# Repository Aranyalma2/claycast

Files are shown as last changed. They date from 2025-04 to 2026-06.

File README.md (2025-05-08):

<p align="center">
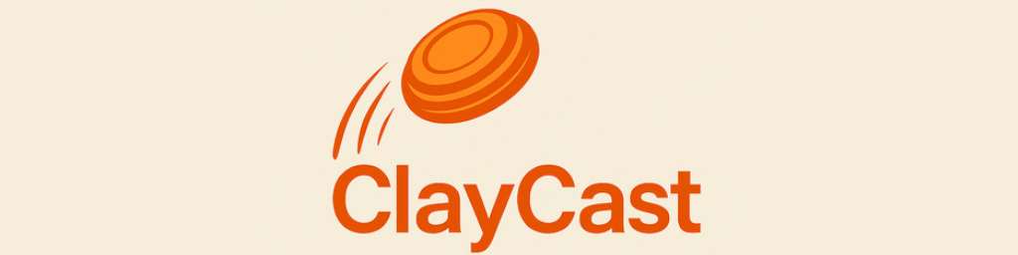
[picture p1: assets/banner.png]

</p>
<p align="center">



</p>

**ClayCast** is a modular wireless control system for clay pigeon shooting ranges.  
It enables field centralized game management via a touchscreen **HMI device**, which controls up to 10 clay thrower machines through a wireless **Modbus RTU** network.  
Communication is handled by **controller node** that act as wireless relays to **client devices** attached to each clay thrower.

## 🎯 Features

- **Modular, multi-device architecture**: HMI (master), Controller (relay), and Client (thrower control)
- **Game management interface** via 7-inch touchscreen HMI
  - Enable/Disable machines (up to 10)
  - Pre-configure next game (max throw, double, triple)
  - Monitor clay disk levels with low-ammo alarms
  - Game screen
  - Summary screen
- **Wireless Modbus RTU bridging** over HC12 (~433MHz)
  - Up to **255 clients** per controller (practically limited to fewer)
  - Reliable full-frame encapsulation (no packet fragmentation)
- **Low-latency protocol** using UART and lightweight firmware
- Built with **Arduino framework**, **Atmega328p**, **ESP32**, and **HC12 modules**
- **Open and customizable** — easy to extend or adapt for other range configurations

## 🧩 Core Components

**ClayCast** consists of three main components:

### 💠 HMI Device
- Acts as the **Modbus RTU Master**
- Human-Machine Interface with touchscreen
- Controls up to **10 clay thrower machines**
- Manages and runs the **preconfigured game**
- Monitors **ammo levels** and triggers alarms if low
- Central command and monitoring unit for the entire system  
[More about here](hmi/README.md)

### 🔸 Controller
- Acts as a wireless Modbus RTU bridge
- Receives Modbus requests from a master device via UART (RS485)
- Encapsulates and broadcasts packets wirelessly to clients
- Receives wireless responses, decapsulates, and forwards them to the master  
[More about here](controller/README.md)

### 🔹 Client
- Identified by a unique Modbus slave address
- Controls an individual clay thrower machine
- Listens for Modbus requests, executes commands (e.g., fire), and returns status
- Response-only device; never initiates communication  
[More about here](client/README.md)

## 📡 Communication Flow

1. HMI sends Modbus RTU request to Controller via UART (RS485).
2. Controller encapsulates and transmits over HC12 radio.
3. Target Client receives, executes, and responds.
4. Controller decapsulates and returns response to HMI.

## 🛠️ Hardware Requirements

- **HMI Device**:
  - Kinco HMI [GL070E](https://en.kinco.cn/productdetail/gl070e90.html)

- **Controller**:
  - Arduino (Atmega328p)
  - HC12 radio module
  - RS485 interface to HMI (Modbus master)

- **Client**:
  - Arduino (Atmega328p)
  - HC12 radio module
  - Clay thrower trigger mechanism (relay, microswitch, etc.)

## 📦 Modbus Support

Clients implement:
- **Trigger register** – Fire the clay thrower
- **Status registers** – Report state, diagnostics, or ammo level

## 🚧 Status & Development Milestones

🛠️ Currently Under Development — Working Prototype Deployed in Test Field

- ✅ **Prototype Hardware Evaluation**  
  Initial testing and validation of temporary hardware components.

- ✅ **Firmware Architecture Design**  
  Core structure and logic for both controller and client firmware defined and implemented.

- ✅ **Interim Hardware Integration**  
  Temporary hardware assembled and tested for early firmware and communication debugging.

- ✅ **Wireless Communication Tester**  
  Radio signal testing module completed to assess transmission range and reliability.

- 🔧 **Final Hardware Assembly** *(In Progress)*  
  Development and deployment of production-ready, dedicated hardware.
  
- 🚀 **Human-Machine Interface (HMI)** *(In Testing)*  
  - Game customizability, fire control, data logging  
  - Ammo monitoring with alarms  
  - Controls up to 10 clay throwers

## 🔀 Alternative use

Create a Modbus RTU bridge over the air with 2 or more **Controllers**. However, radio medium usage is not controlled, so it is easy to cause interference. Incidentally it does not include any error detection and/or correction, leaving everything to the application layer protocol.
Not ready for any production usage.

---

## 📜 License

This project is licensed under the MIT License. See the [LICENSE](LICENSE.md) file for details.

---

## 🤝 Contributions

Made with ❤️ by <a href="https://github.com/Aranyalma2" target="_blank">Aranyalma2</a>

This is a self-maintained project. Feel free to use, fork, or modify it. Feedback and suggestions are always welcome!

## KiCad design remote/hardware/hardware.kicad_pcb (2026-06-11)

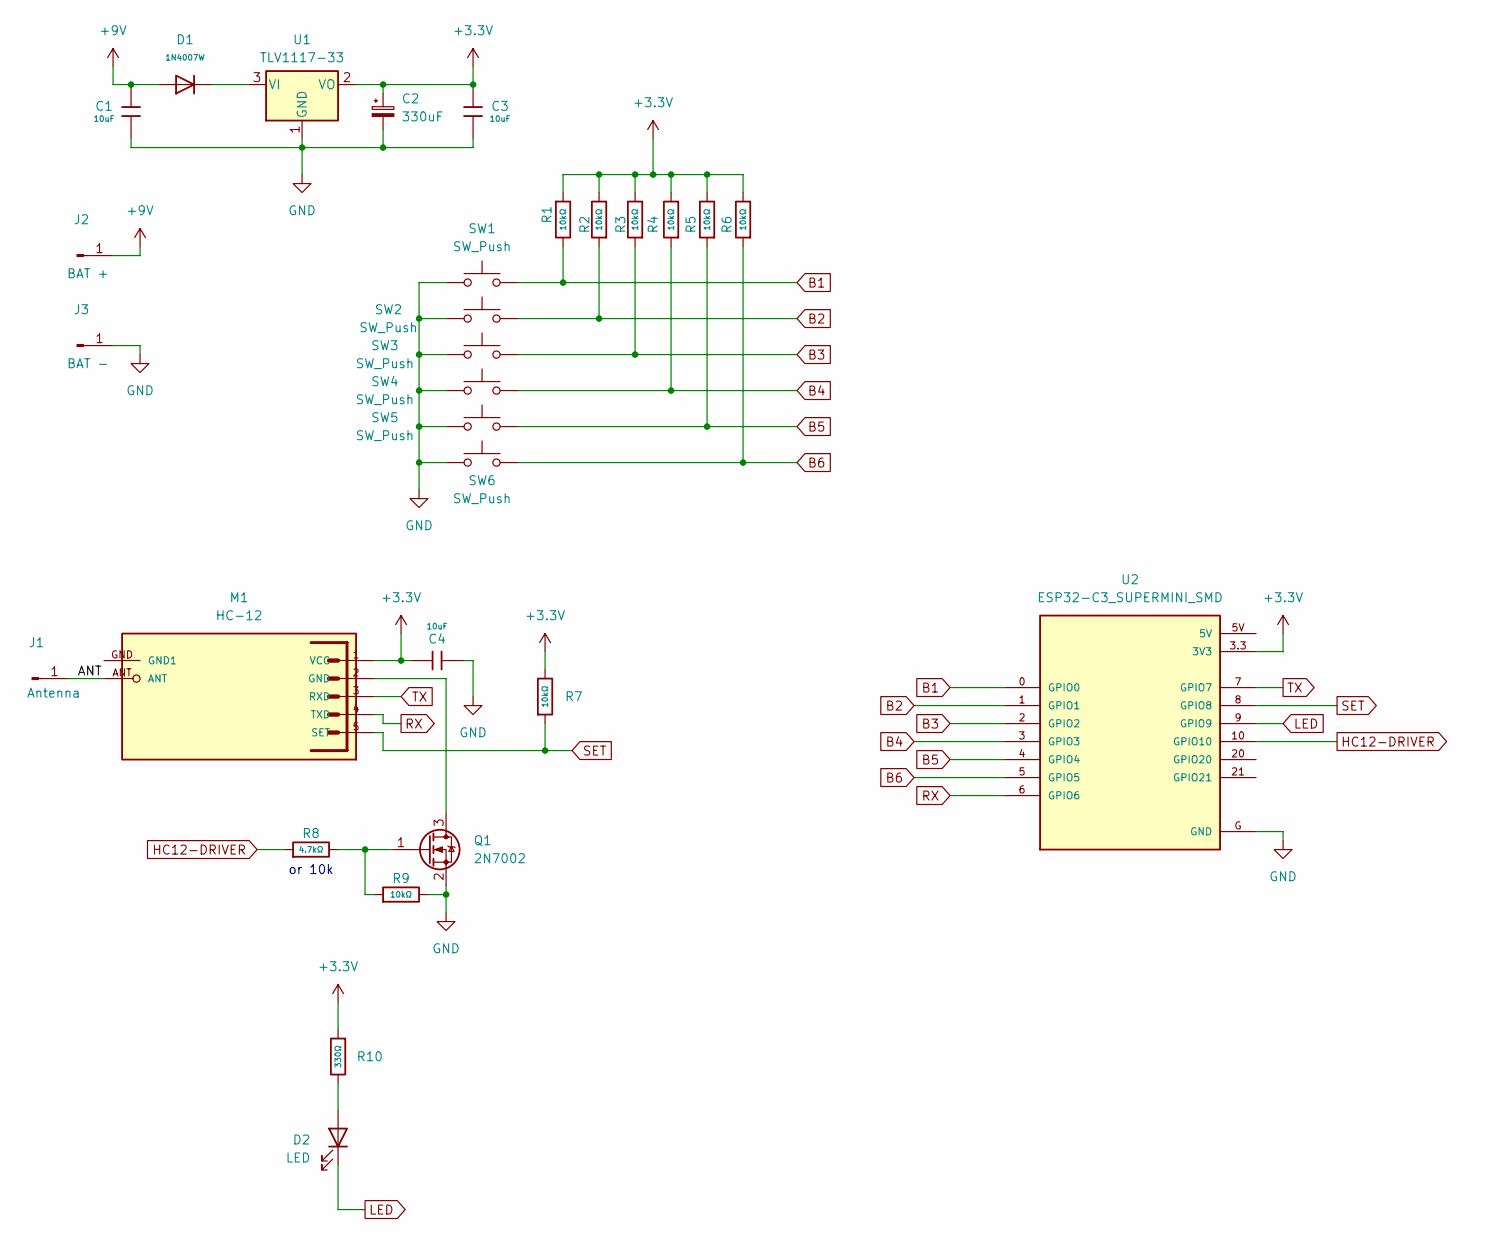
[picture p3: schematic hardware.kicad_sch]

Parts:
C1, C3, C4: 10uF; C_1206; Voltage Rated 6V; Tolerance ±10%; Part CL31A106KBHNNNE; LCSC C13585
C2: 330uF; CP_Radial_D6.3mm_P2.50mm
D1: 1N4007W; D_SMB; Part 1N4007W; LCSC C18199088
D2: LED; LED_1206_3216Metric_Pad1.42x1.75mm_HandSolder
J1: Antenna; PinHeader_1x01_P1.00mm_Vertical
J2: BAT +; PinHeader_1x01_P1.00mm_Vertical
J3: BAT -; PinHeader_1x01_P1.00mm_Vertical
M1: HC-12; MA05-1
Q1: 2N7002; SOT-23
R1, R2, R3, R4, R5, R6, R7, R9: 10kΩ; R_0805; Overload Voltage (Max) 200V; Tolerance ±1%; Part 1206W4F1002T5E; LCSC C17902
R8: 4.7kΩ; R_0805; Overload Voltage (Max) 200V; Tolerance ±1%; Part 1206W4F1002T5E; LCSC C17902
R10: 330Ω; R_1206
SW1, SW2, SW3, SW4, SW5, SW6: SW_Push; SW_Push_1P1T_NO_E-Switch_TL3301NxxxxxG
U1: TLV1117-33; TO-252-2
U2: ESP32-C3_SUPERMINI_SMD; MODULE_ESP32-C3_SUPERMINI

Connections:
+3.3V: C2.1, C3.1, C4.1, M1.1 (VCC), R1.1, R2.2, R3.2, R4.2, R5.2, R6.2, R7.2, R10.1, U1.2 (VO), U2.3.3 (3V3)
+9V: C1.1, D1.2, J2.1
/ANT: J1.1, M1.ANT
B1: R1.2, SW1.1, U2.0 (GPIO0)
B2: R2.1, SW2.1, U2.1 (GPIO1)
B3: R3.1, SW3.1, U2.2 (GPIO2)
B4: R4.1, SW4.1, U2.3 (GPIO3)
B5: R5.1, SW5.1, U2.4 (GPIO4)
B6: R6.1, SW6.1, U2.5 (GPIO5)
GND: C1.2, C2.2, C3.2, C4.2, J3.1, Q1.2 (S), R9.2, SW1.2, SW2.2, SW3.2, SW4.2, SW5.2, SW6.2, U1.1 (GND), U2.G (GND)
HC12-DRIVER: R8.1, U2.10 (GPIO10)
LED: D2.1 (K), U2.9 (GPIO9)
unnamed: D2.2 (A), R10.2
unnamed: M1.2 (GND), Q1.3 (D)
unnamed: Q1.1 (G), R8.2, R9.1
unnamed: D1.1, U1.3 (VI)
RX: M1.4 (TXD), U2.6 (GPIO6)
SET: M1.5 (SET), R7.1, U2.8 (GPIO8)
TX: M1.3 (RXD), U2.7 (GPIO7)

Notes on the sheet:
or 10k

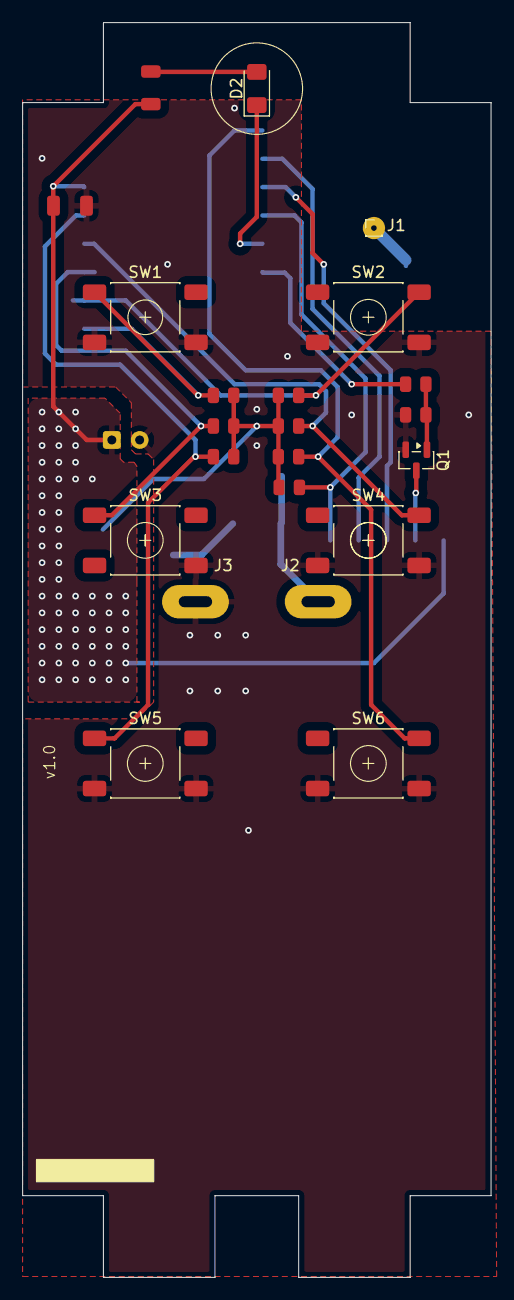
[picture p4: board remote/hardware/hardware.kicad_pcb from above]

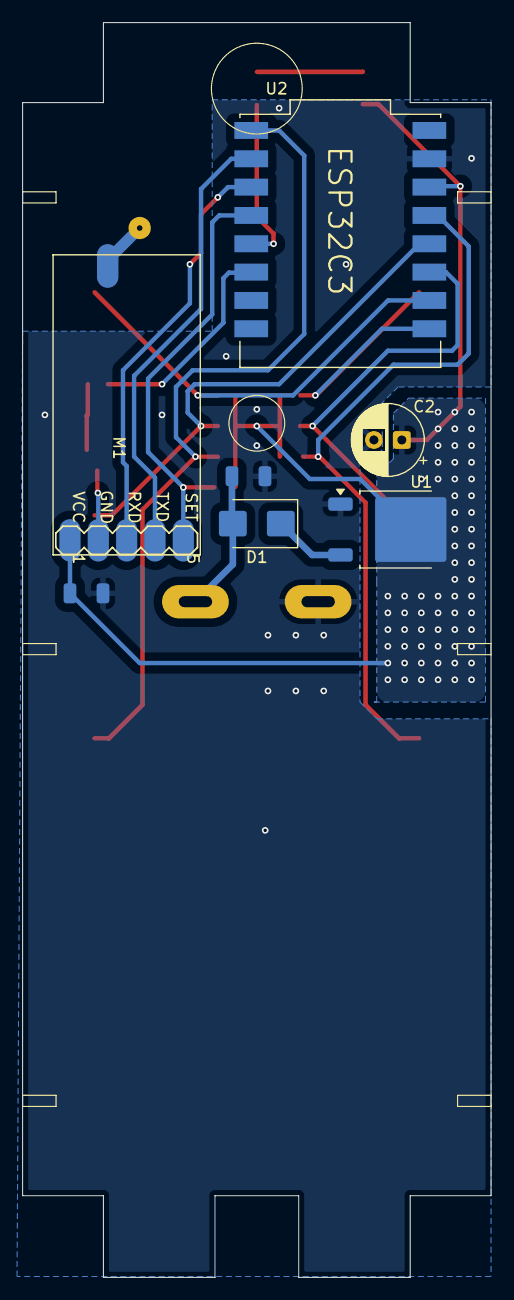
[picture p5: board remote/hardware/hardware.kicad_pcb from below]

Board: 2 copper layers, 42.0 x 112.5 mm, 29 parts (7 on the bottom side), 19 nets.

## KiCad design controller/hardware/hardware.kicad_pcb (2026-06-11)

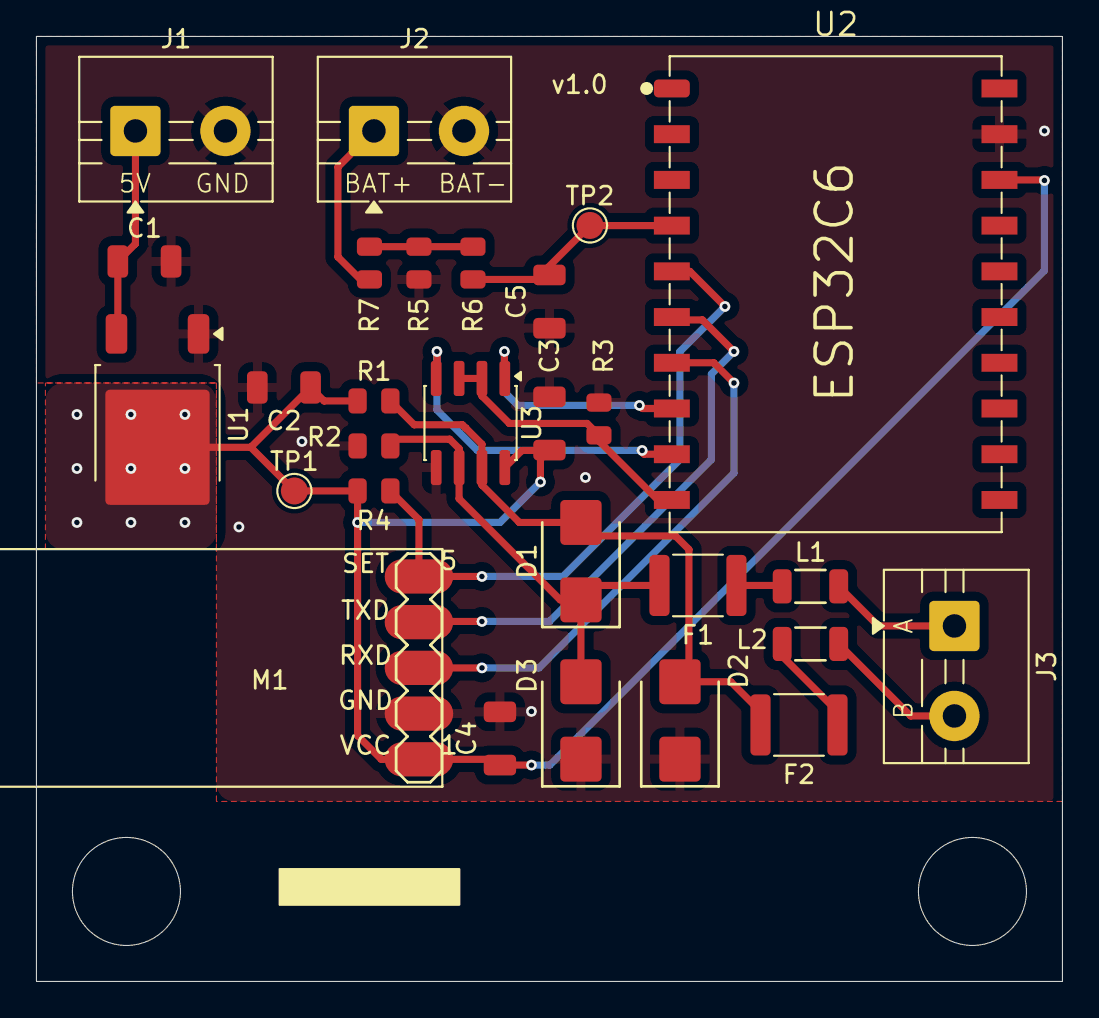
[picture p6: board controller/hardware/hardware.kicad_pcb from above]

Board: 2 copper layers, 57.0 x 52.5 mm, 28 parts (0 on the bottom side), 18 nets.

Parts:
C1, C2, C4: 10uF; C_1206
C3, C5: 100nF; C_1206
D1, D2, D3: SMBJ12CA; D_SMB
F1, F2: BSMD1812-100-30V
J1, J2, J3: Screw_Terminal_01x02; TerminalBlock_MaiXu_MX126-5.0-02P_1x02_P5.00mm
L1, L2: 10uH; L_1206
M1: HC-12; MA05-1
R1, R2, R3, R4: 10kΩ; R_0805
R5: 1MΩ; R_0805
R6: 1kΩ; R_0805
R7: 100kΩ; R_0805
TP1: 3V3; TestPoint_Pad_D1.5mm
TP2: BAT_V; TestPoint_Pad_D1.5mm
U1: TLV1117-33; TO-252-2
U2: ESP32-C6-SuperMini; ESP32-C6-SuperMini_SMD
U3: MAX3485; SOIC-8_3.9x4.9mm_P1.27mm

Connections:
+3.3V: C2.1, C3.1, C4.1, M1.1 (VCC), R1.1, R4.2, TP1.1, U1.2 (VO), U2.13 (3V3), U3.8 (VCC)
+5V: C1.1, J1.1, U1.3 (VI)
+BATT: J2.1, R5.2
BAT_MEASURE: C5.2, R6.1, TP2.1, U2.4 (GPIO1)
GND: C1.2, C2.2, C3.2, C4.2, C5.1, D2.1, D3.1, J1.2, J2.2, M1.2 (GND), R2.2, R3.2, R7.1, U1.1 (GND), U2.12 (GND), U3.5 (GND)
unnamed: F1.2, L1.1
unnamed: F2.2, L2.1
unnamed: R5.1, R6.2, R7.2
unnamed: D1.1, D3.2, F1.1, R2.1, U3.6 (A)
unnamed: D1.2, D2.2, F2.1, R1.2, U3.7 (B)
RS485-1_A: J3.1, L1.2
RS485-1_B: J3.2, L2.2
RX: M1.4 (TXD), U2.6 (GPIO3)
RX1: U2.8 (GPIO5), U3.1 (RO)
SET: M1.5 (SET), R4.1, U2.5 (GPIO2)
TX: M1.3 (RXD), U2.7 (GPIO4)
TX1: U2.9 (GPIO6), U3.4 (DI)
TX1_EN: R3.1, U2.10 (GPIO7), U3.2 (~RE), U3.3 (DE)

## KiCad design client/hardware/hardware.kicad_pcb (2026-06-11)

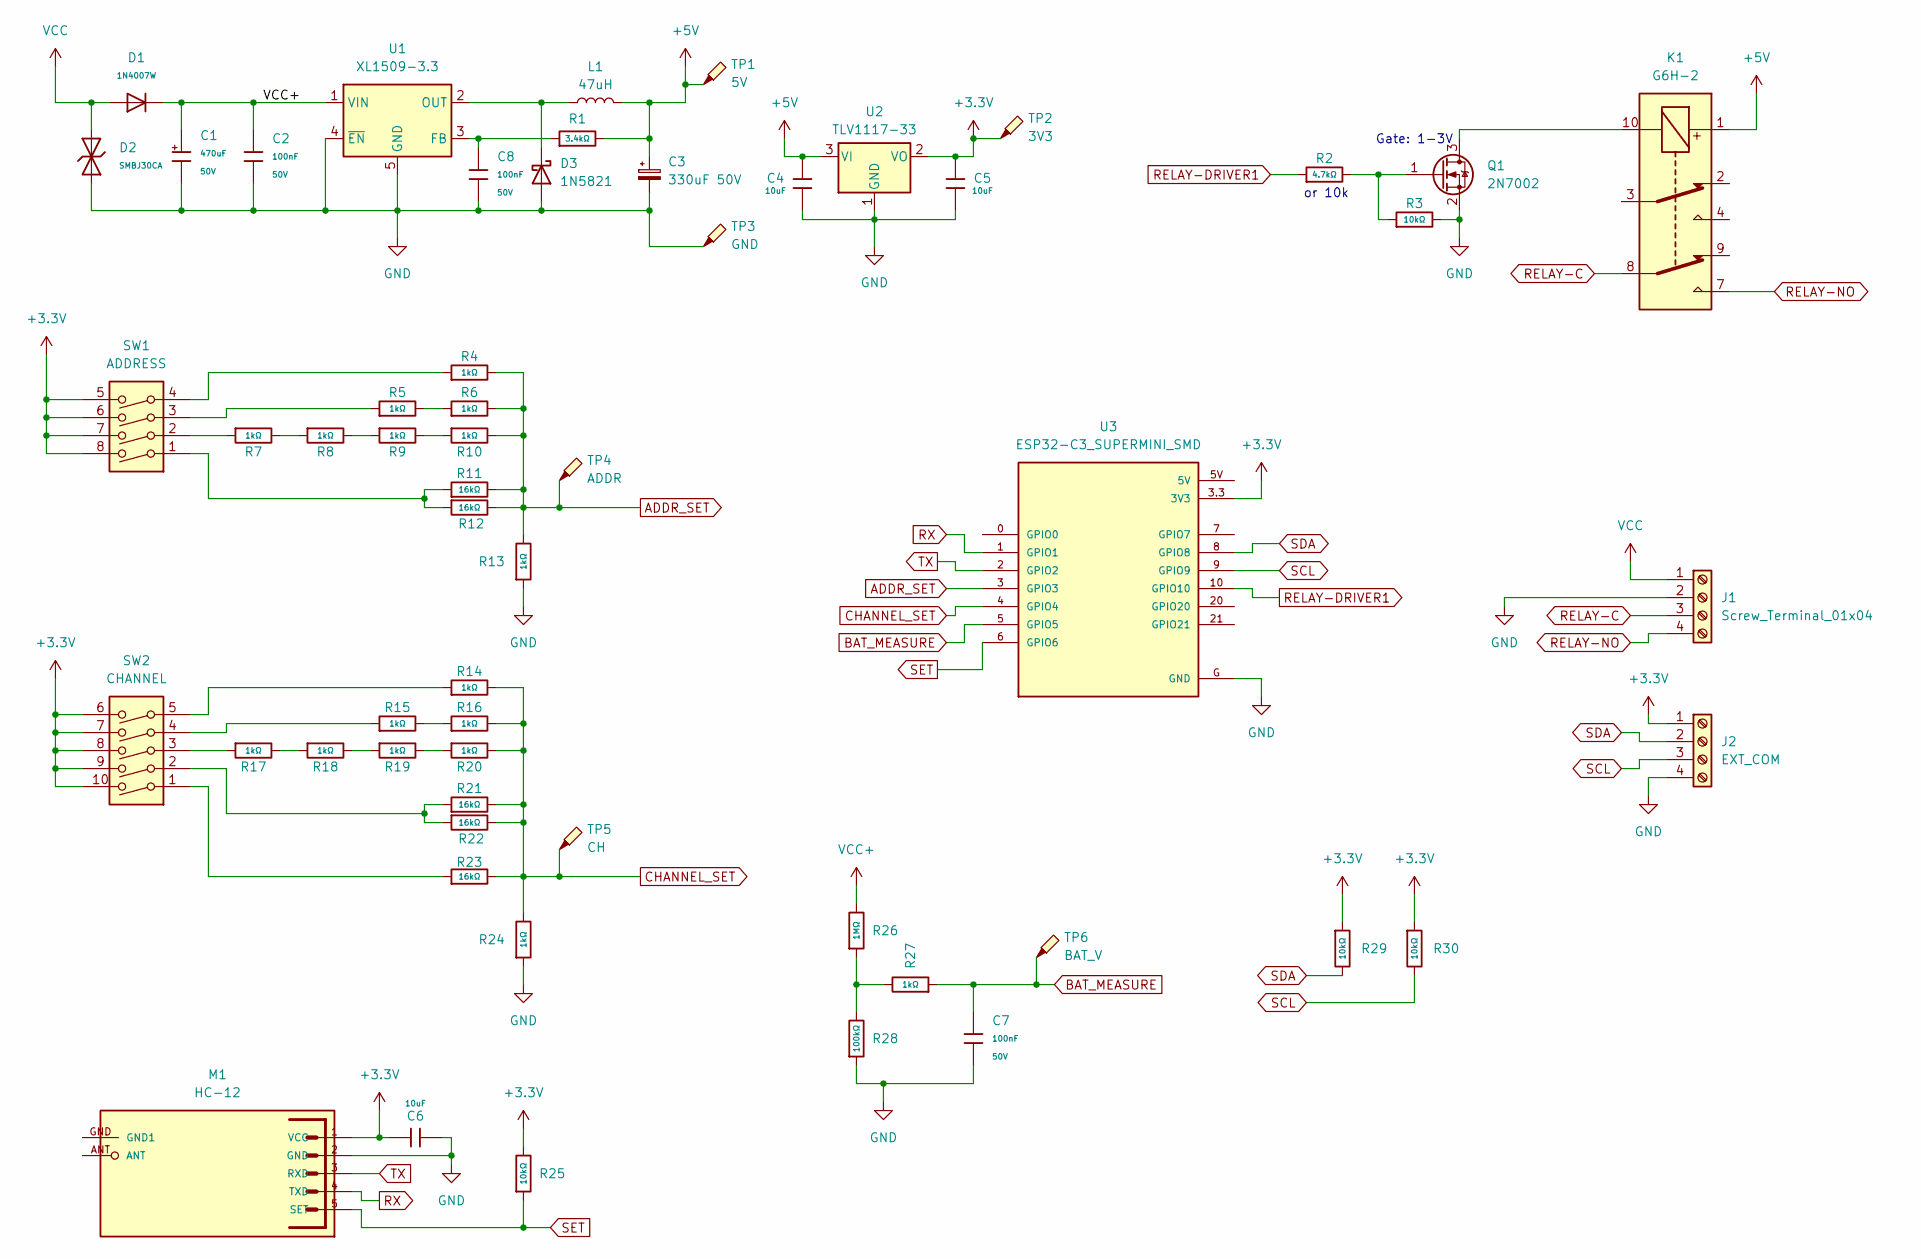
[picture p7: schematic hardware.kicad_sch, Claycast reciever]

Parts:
C1: 470uF; C_Plugin,D10xL16mm; Voltage Rated 50V; Part EGT477M1HG16RRS0P; LCSC C3015599
C2, C7, C8: 100nF; C_1206; Voltage Rated 50V; Tolerance ±10%; Part CL31B104KBCNNNC; LCSC C24497
C3: 330uF 50V; CP_Radial_D6.3mm_P2.50mm
C4, C5, C6: 10uF; C_1206; Voltage Rated 6V; Tolerance ±10%; Part CL31A106KBHNNNE; LCSC C13585
D1: 1N4007W; D_SMB; Part 1N4007W; LCSC C18199088
D2: SMBJ30CA; D_SMB; Breakdown Voltage 33.3V; Part SMBJ30CA; LCSC C2925441
D3: 1N5821; D_SMB
J1: Screw_Terminal_01x04; General Connector 4P 3.5mm - Socket
J2: EXT_COM; JST_PH_B4B-PH-K_1x04_P2.00mm_Vertical
K1: G6H-2; Relay_DPDT_Omron_G6H-2
L1: 47uH; L_Radial_D7.0mm_P3.00mm
M1: HC-12; MA05-1
Q1: 2N7002; SOT-23
R1: 3.4kΩ; R_0805; Overload Voltage (Max) 150V; Tolerance ±1%; Part 0805W8F3303T5E; LCSC C17629
R2: 4.7kΩ; R_0805; Overload Voltage (Max) 200V; Tolerance ±1%; Part 1206W4F1002T5E; LCSC C17902
R3, R25, R29, R30: 10kΩ; R_0805; Overload Voltage (Max) 200V; Tolerance ±1%; Part 1206W4F1002T5E; LCSC C17902
R4, R5, R6, R7, R8, R9, R10, R13, R14, R15, R16, R17, R18, R19, R20, R24, R27: 1kΩ; R_0805; Overload Voltage (Max) 200V; Tolerance ±1%; Part 1206W4F1002T5E; LCSC C17902
R11, R12, R21, R22, R23: 16kΩ; R_0805; Overload Voltage (Max) 200V; Tolerance ±1%; Part 1206W4F1002T5E; LCSC C17902
R26: 1MΩ; R_0805; Overload Voltage (Max) 200V; Tolerance ±1%; Part 1206W4F1002T5E; LCSC C17902
R28: 100kΩ; R_0805; Overload Voltage (Max) 200V; Tolerance ±1%; Part 1206W4F1002T5E; LCSC C17902
SW1: ADDRESS; SW_DIP_SPSTx04_Slide_9.78x12.34mm_W7.62mm_P2.54mm
SW2: CHANNEL; SW_DIP_SPSTx05_Slide_9.78x14.88mm_W7.62mm_P2.54mm
TP1: 5V; TestPoint_Pad_D1.5mm
TP2: 3V3; TestPoint_Pad_D1.5mm
TP3: GND; TestPoint_Pad_D1.5mm
TP4: ADDR; TestPoint_Pad_D1.5mm
TP5: CH; TestPoint_Pad_D1.5mm
TP6: BAT_V; TestPoint_Pad_D1.5mm
U1: XL1509-3.3; SOIC-8_3.9x4.9mm_P1.27mm
U2: TLV1117-33; TO-252-2
U3: ESP32-C3_SUPERMINI_SMD; MODULE_ESP32-C3_SUPERMINI

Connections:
+3.3V: C5.1, C6.1, J2.1, M1.1 (VCC), R25.2, R29.1, R30.1, SW1.5, SW1.6, SW1.7, SW1.8, SW2.6, SW2.7, SW2.8, SW2.9, SW2.10, TP2.1, U2.2 (VO), U3.3.3 (3V3)
+5V: C3.1, C4.1, K1.1, L1.2, R1.2, TP1.1, U2.3 (VI)
ADDR_SET: R4.2, R6.2, R10.2, R11.2, R12.2, R13.2, TP4.1, U3.3 (GPIO3)
BAT_MEASURE: C7.2, R27.1, TP6.1, U3.5 (GPIO5)
CHANNEL_SET: R14.2, R16.2, R20.2, R21.2, R22.2, R23.2, R24.2, TP5.1, U3.4 (GPIO4)
GND: C1.2, C2.2, C3.2, C4.2, C5.2, C6.2, C7.1, C8.2, D2.1, D3.2 (A), J1.2, J2.4, M1.2 (GND), Q1.2 (S), R3.2, R13.1, R24.1, R28.1, TP3.1, U1.4 (~EN), U1.5 (GND), U1.6 (GND), U1.7 (GND), U1.8 (GND), U2.1 (GND), U3.G (GND)
unnamed: D3.1 (K), L1.1, U1.2 (OUT)
unnamed: K1.10, Q1.3 (D)
unnamed: Q1.1 (G), R2.2, R3.1
unnamed: R4.1, SW1.4
unnamed: R5.1, SW1.3
unnamed: R5.2, R6.1
unnamed: R7.1, SW1.2
unnamed: R7.2, R8.1
unnamed: R8.2, R9.1
unnamed: R9.2, R10.1
unnamed: R11.1, R12.1, SW1.1
unnamed: R14.1, SW2.5
unnamed: R15.1, SW2.4
unnamed: R15.2, R16.1
unnamed: R17.1, SW2.3
unnamed: R17.2, R18.1
unnamed: R18.2, R19.1
unnamed: R19.2, R20.1
unnamed: R21.1, R22.1, SW2.2
unnamed: R23.1, SW2.1
unnamed: R26.1, R27.2, R28.2
unnamed: C8.1, R1.1, U1.3 (FB)
RELAY-C: J1.3, K1.8
RELAY-DRIVER1: R2.1, U3.10 (GPIO10)
RELAY-NO: J1.4, K1.7
RX: M1.4 (TXD), U3.1 (GPIO1)
SCL: J2.3, R30.2, U3.9 (GPIO9)
SDA: J2.2, R29.2, U3.8 (GPIO8)
SET: M1.5 (SET), R25.1, U3.6 (GPIO6)
TX: M1.3 (RXD), U3.2 (GPIO2)
VCC: D1.2, D2.2, J1.1
VCC+: C1.1, C2.1, D1.1, R26.2, U1.1 (VIN)

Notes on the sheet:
or 10k
Gate: 1-3V

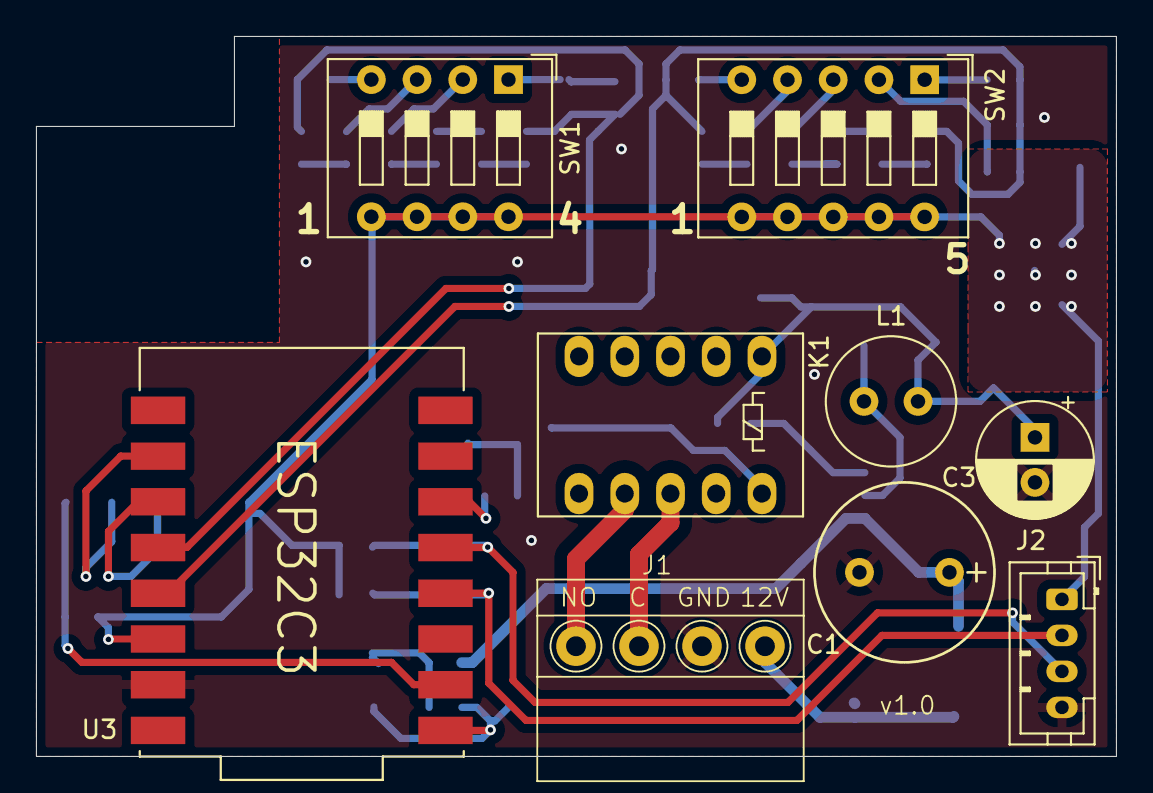
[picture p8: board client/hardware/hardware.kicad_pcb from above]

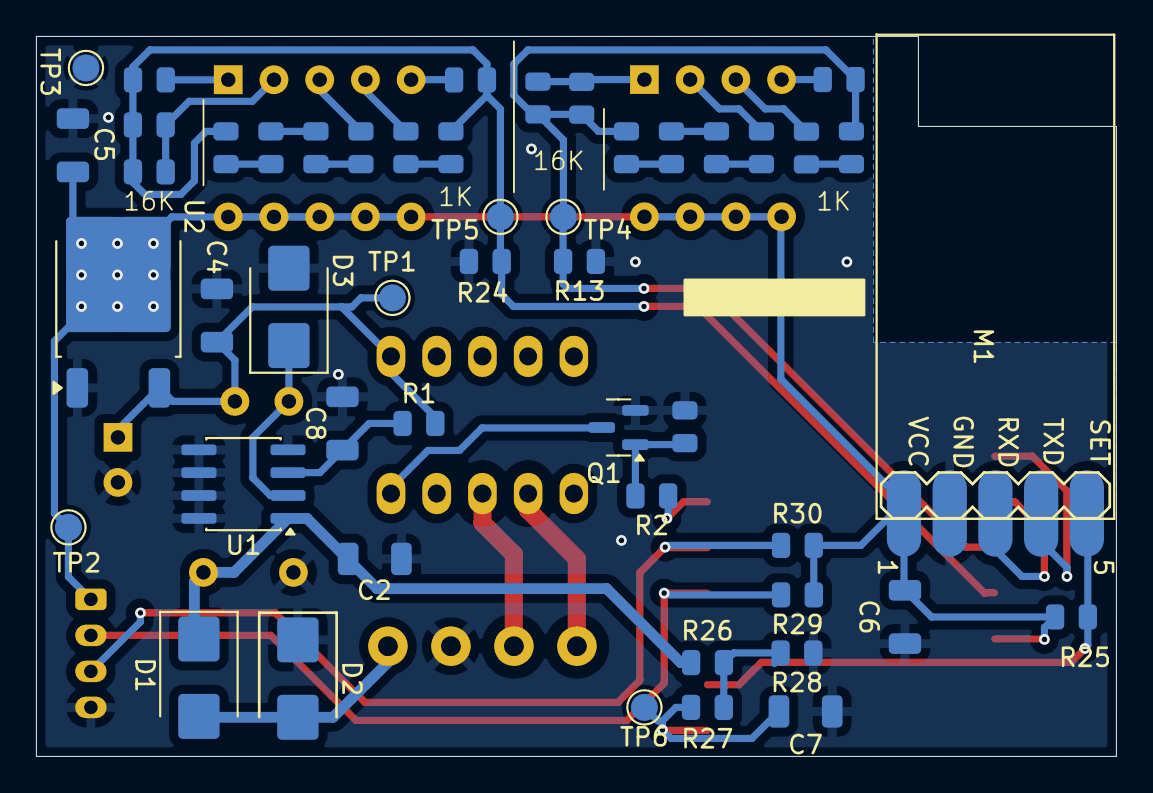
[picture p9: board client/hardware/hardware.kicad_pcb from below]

Board: 2 copper layers, 60.0 x 40.0 mm, 58 parts (49 on the bottom side), 38 nets.

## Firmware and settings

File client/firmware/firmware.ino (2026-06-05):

#include "src/config.h"
#include "src/SetupLoader.h"
#include <Arduino.h>
#include <HC12Transporter.h>

// Encryption key (just for set, but no practical use)
static const uint8_t SHARED_KEY[16] = {
    0xDE, 0xAD, 0xBE, 0xEF, 0xCA, 0xFE, 0xBA, 0xBE,
    0x01, 0x23, 0x45, 0x67, 0x89, 0xAB, 0xCD, 0xEF};

HC12Driver radio;
RadioTransport transport;

uint32_t triggerTime = 0;

// --- onReceive callback (fires from background task) ---
// sendAsync() is safe here. send() is NOT safe here -- it will deadlock.
static void onPacket(uint8_t src, PacketType type,
                     const uint8_t* data, uint8_t len) {
    switch (type) {
        case PacketType::DATA:
        Serial.printf("DATA from 0x%02X (%d bytes)\n", src, len);
        if(len > 1) { return; }
            switch (data[0]) {
                case 0x01:
                    Serial.println(F("Trigger received"));
                    triggerTime = millis();
                    digitalWrite(RELAY_PIN, HIGH);
                    break;
                case 0x02:
                    Serial.println(F("Get Battery"));
                    uint16_t batteryVoltage = SetupLoader::getBatteryVoltage();
                    transport.sendAsync(src, PacketType::DATA, &batteryVoltage, 2);
                    break;
                default:
                    break;
            }
            break;

        case PacketType::PING:
            // Reply with a PONG carrying this node's radio address.
            Serial.printf("PING from 0x%02X -> PONG\n", src);
            {
                // Payload: [mylocal channel and address]
                uint8_t pong[2] = {SetupLoader::getChannel(), SetupLoader::getAddress()};
                transport.sendAsync(src, PacketType::PONG, pong, 2);
            }
            break;

        default:
            break;
    }
}

void setup() {
    Serial.begin(115200);
    SetupLoader::init();

    // --- HC-12 configuration ---

    HC12Config hcCfg = HC12_DEFAULT_CONFIG;
    hcCfg.channel = SetupLoader::getChannel();
    hcCfg.baud = 9600;

    if (!radio.begin(&Serial1, HC12_SET_PIN, HC12_RX_PIN, HC12_TX_PIN, hcCfg)) {
        Serial.println(F("HC-12 init FAILED"));
        delay(2000);
        ESP.restart();
    }
    Serial.println(F("HC-12 OK"));

    // --- Transport configuration ---
    TransportConfig tCfg = TRANSPORT_DEFAULT_CONFIG;
    tCfg.localAddr = SetupLoader::getAddress() + 0x10;
    tCfg.autoPowerEnabled = false;
    memcpy(tCfg.encryptionKey, SHARED_KEY, 16);

    if (!transport.begin(&radio, tCfg)) {
        Serial.println(F("Transport init FAILED"));
        delay(2000);
        ESP.restart();
    }

    transport.onReceive(onPacket);

    if (!transport.startTask()) {
        Serial.println(F("Transport task START FAILED"));
        delay(2000);
        ESP.restart();
    }

    Serial.printf("[SLAVE 0x%02X] Transport ready\n", SetupLoader::getAddress() + 0x10);
}

void loop() {
    if (triggerTime + TRIGGER_TIME < millis()) {
        digitalWrite(RELAY_PIN, LOW);
    }
}

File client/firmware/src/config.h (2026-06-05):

#ifndef __CONFIG_H__
#define __CONFIG_H__

// RADIO PINS
#define HC12_RX 1
#define HC12_TX 2
#define HC12_SET 6

// ANALOG PINS
#define CHANNEL_SET 4
#define NODE_ADDRESS 3
#define BATTERY_MEASUREMENT_PIN 5

// I2C PINS
#define I2C_SDA 8
#define I2C_SCL 9

// RELAY PINS
#define RELAY_PIN 10

// TRIGGER TIME
#define TRIGGER_TIME 1000

#endif  // __CONFIG_H__

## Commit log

2025-04-30 Kinco HMI
    Human machine interface and game controller
    Up to 10 machine
    Support Hungarian language only
    *Use [Kinco DTools V4.5.0.1](https://en.kinco.cn/download/hmisoftware.html)*
    [current_project_name_file.csv]
2026-05-27 remove the v1 files
    [current_project_name_file.csv]
2026-06-05 receiver pcb v1
    [hardware.kicad_pcb, hardware.kicad_sch]
2026-06-05 controller init
    [hardware.kicad_pcb, hardware.kicad_sch]
2026-06-05 update to kicad v9
    [hardware.kicad_pcb, hardware.kicad_sch]
2026-06-05 hw updates
    [hardware.kicad_pcb, hardware.kicad_sch]
2026-06-06 remote init
    [hardware.kicad_pcb, hardware.kicad_sch]
2026-06-11 final v1.0 hardware
    [hardware.kicad_pcb, hardware.kicad_sch]
